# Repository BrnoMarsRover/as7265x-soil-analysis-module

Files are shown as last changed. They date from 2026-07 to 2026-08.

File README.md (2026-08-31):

# AS7265x Soil Analysis Module

> Multispectral soil-analysis subsystem developed for the **Brno Mars Rover / Freya** science payload.






<p align="center">
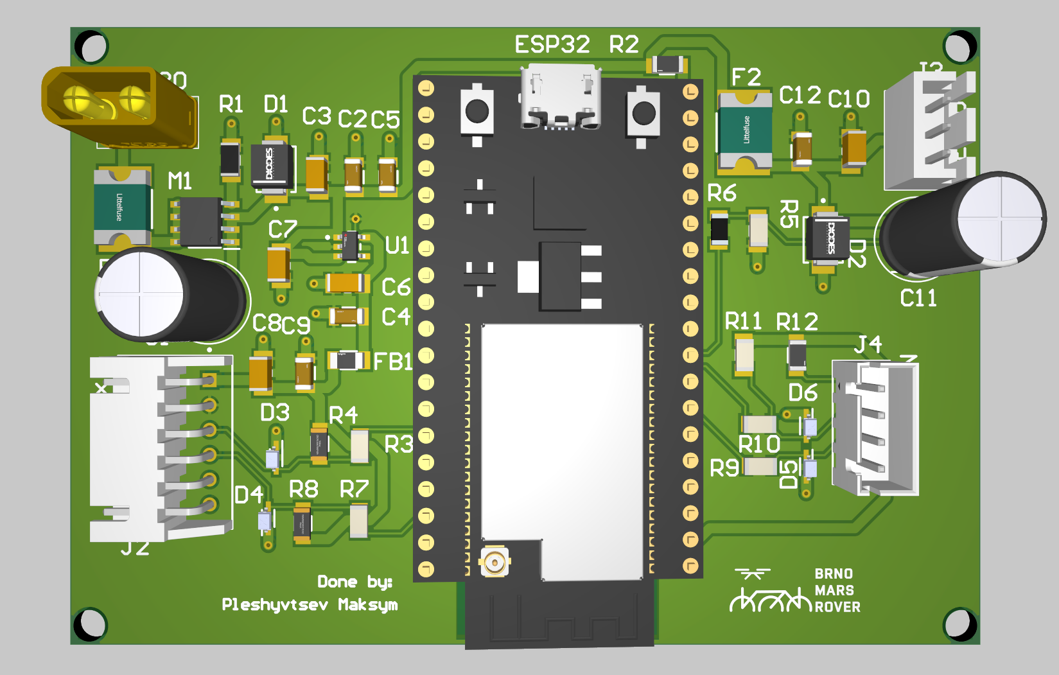
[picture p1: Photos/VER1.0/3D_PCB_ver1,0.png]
AS7265x Soil Analysis Module PCB V1.0
  
</p>

---

# 1. System Architecture & Sensor Task

## Overview

The **AS7265x Soil Analysis Module** is a rover-mounted subsystem for comparative multispectral analysis of soil and geological samples.

The system uses the **AS7265x 18-channel VIS-NIR spectral sensor** to measure reflected light between approximately **410 nm and 940 nm**. An ESP32 controls the sensor, a **four-slot sample carousel** driven by a Waveshare **ST3215** serial bus servo, and the illumination.

The ESP32 is a **passive command-controlled instrument**. It performs no automatic movement and no automatic measurement: the main computer is the mission controller and issues one JSON command at a time over the USB serial link. The ESP32 moves the carousel, reads the sensor and returns a raw spectrum; all scientific processing and all persistent sample data live on the main computer.

The project combines:

- custom PCB design;
- protected power distribution;
- embedded control;
- multispectral data acquisition;
- calibration and measurement methodology;
- spectral database development;
- mechanical and rover-system integration.

The current PCB V1.0 provides the core functionality required for the competition while remaining open to future sensor and hardware improvements.

---

## Engineering Scope

The project was developed from system concept to an assembled and operational hardware platform.

The engineering work includes:

- defining the overall science-module architecture;
- selecting the sensor, controller, actuator, connectors, and protection components;
- designing the complete schematic in Altium Designer;
- creating a custom two-layer carrier PCB;
- designing protected 5 V and 3.3 V power branches;
- integrating I²C, UART, PWM, and illumination interfaces;
- preparing the component BOM and purchasing documentation;
- assembling and debugging the first PCB revision;
- developing ESP32 firmware for sensor and servo control;
- creating a structured spectral material database;
- defining calibration and sample-preparation procedures;
- preparing the system for mechanical integration with the Freya rover.

---

## System Operation

The module is command-driven. Nothing moves and nothing is measured until the rover main computer asks for it.

1. The operator aligns physical Slot 1 with the loading hole and confirms it (`sync_position`).
2. `select_slot` brings the chosen slot to the loading hole, one 90 deg step per slot.
3. The PC creates a persistent Sample record with an ID and science metadata.
4. The external rover arm deposits soil; the operator confirms that it happened.
5. `measure_raw` rotates the same physical slot to the scanner, settles, and acquires one **raw** 18-channel spectrum.
6. The PC corrects that spectrum with the **fixed** stored dark and white references.
7. The normalized spectrum is compared against **every** material in the reference database.
8. An automatic, deliberately conservative interpretation is generated.
9. The complete scientific record is written to the PC archive — the same record opened in step 3.

```mermaid
flowchart LR
    SAMPLE[Soil sample in carousel slot]
    LIGHT[Controlled illumination]
    SENSOR[AS7265x spectral sensor]
    ESP[ESP32 hardware controller]
    SERVO[ST3215 serial bus servo, 4-slot carousel]
    PC[PC mission controller]
    BD[BD science layer]
    DATABASE[(database.json<br/>reference materials)]
    REFS[(references.json<br/>fixed white + dark)]
    STORE[(PC data/samples<br/>measured samples)]

    ESP -->|GPIO| LIGHT
    LIGHT --> SAMPLE
    SAMPLE -->|Reflected VIS-NIR light| SENSOR
    ESP <-->|I²C| SENSOR
    ESP -->|timed PWM| SERVO
    ESP -->|USB serial JSON: RAW spectrum| PC
    PC -->|raw| BD
    DATABASE --> BD
    REFS --> BD
    BD -->|normalized + matches| PC
    PC --> STORE
```

---

## Sample Carousel

The sample mechanism is a **four-slot carousel** on a full 360 deg axis,
driven by a Waveshare **ST3215 serial bus servo**. The ST3215 has a
4096-count absolute magnetic encoder and runs its own closed position
loop, so every movement is commanded in encoder counts and then
**verified by reading the encoder back**.

```
4 slots, 90 deg apart
loader and scanner exactly 180 deg apart = 2 slots

    load_slot = ((scan_slot - 1 + 2) % 4) + 1
```

The mapping is its own inverse: Slot 1 at the loader necessarily means
Slot 3 at the scanner.

### Two fixed positions

```
SCAN   the slot under the AS7265x
LOAD   the slot under the loading hole
```

A measurement swings the selected slot 180 deg to the scanner, acquires
WHITE, UV and IR spectra, and swings it 180 deg back, so the sample ends
exactly where it started.

### Software position tracking

The carousel has no limit switch, no Hall sensor and no physical index,
so nothing can tell the firmware which physical slot the operator calls
Slot 1. That is declared once, by hand, through option `[0]` — which
never moves anything. The declaration also captures the ST3215's encoder
reading, tying the logical model to a real measurement.

Position confidence is **runtime state and deliberately forgotten on
reset**. It is also dropped whenever the firmware can no longer vouch
for it: after a servo reconnect, after torque is released so the
carousel can be turned by hand, after a stop mid-movement, and after any
movement that fails to verify. Normal movement is then refused until the
operator re-synchronizes. The firmware never guesses.

### Logical geometry is not actuator calibration

One slot is 90 deg, always — even where the real mechanism needs a small
correction. The correction is a mechanical calibration; the 90 deg is a
fact about the carousel, and nothing tunes it.

### Fine alignment

Option `[5]` applies a small physical correction, bounded by
`MAX_FINE_ADJUST_DEG`. It does **not** renumber slots, redefine the
origin or act as a hidden whole-slot move: after a fine adjustment the
logical slot identity is exactly what it was.

### Safe measurement order

The sensor is proved usable **before** the mechanism moves. A sensor
fault should not leave a sample stranded at the scanner, and a carousel
that has already turned cannot un-turn to prove a point.

## Servo Calibration

Nothing here is a timing calibration. The ST3215 is commanded in encoder
counts and verified from the encoder afterwards, so the values in
`ESP32/config.py` are engineering settings rather than numbers to be
trimmed against a stopwatch:

| Setting | Meaning |
|---|---|
| `ST3215_MODE = 3` | step servo — the goal register IS a relative step count |
| `ST3215_SPEED` | goal speed in encoder steps per second |
| `ST3215_ACCELERATION` | start/stop ramp, in units of 100 steps/s^2 |
| `ST3215_POSITION_TOLERANCE` | how close counts as arrived |
| `ST3215_SETTLE_MS` | ring-down before the encoder reading that decides |

Step servo mode is what a carousel needs: a carousel turns forever in
one direction, and an absolute single-turn target would have to cross
the 4095/0 seam and send the mechanism the long way round.

`ST3215_POSITION_TOLERANCE` is **conservative and not yet measured on
the real mechanism**. Tighten it once the true repeatability is known —
but a tolerance that is too tight turns ordinary backlash into a failed
measurement.

## Main Features

- 18-channel spectral acquisition from approximately 410 nm to 940 nm;
- ESP32-based sensor and actuator control;
- four-slot 360° sample carousel with encoder-verified movement;
- deterministic USB-serial JSON command protocol for the main computer;
- persistent scientific sample storage on the main computer;
- fixed white and dark calibration references, never re-measured mid-run;
- comparison against every material in the spectral reference database;
- automatic, conservative interpretation of each measurement;
- USB programming and debugging through the ESP32 development board;
- protected 5 V rover power input;
- filtered 3.3 V sensor supply;
- separate protected servo power branch;
- MOSFET-controlled external illumination;
- JST-XH connectors for external modules;
- 1206 passive components for easier manual assembly.

---

# 2. Hardware

## Hardware V1.0

The final hardware is built around a custom two-layer carrier PCB connecting the ESP32 controller, AS7265x spectral sensor and carousel servo.

## Main Components

| Function | Component | Purpose |
|---|---|---|
| Controller | ESP-WROOM-32 development board with CP2102 | Sensor control, carousel control, USB serial communication and data processing |
| Spectral sensor | AS7265x multispectral triad | 18-channel VIS-NIR measurement |
| Servo | Waveshare ST3215 serial bus servo | Encoder-verified rotation of the four-slot sample carousel, on UART2 |
| Sensor regulator | TLV75533PDBVR | Protected 3.3 V sensor supply |
| Reverse-polarity protection | AO4407A | Protects the board from incorrect input polarity |
| Main and servo fuses | Littelfuse 2920L300/15DR | Resettable overcurrent protection |
| Input and servo TVS | SMBJ5.0A-13-F | Suppression of voltage transients |
| Sensor filtering | BLM31PG121SN1L | High-frequency noise filtering |
| Illumination switch | AO3400A | Low-side control of external illumination |
| Main power connector | XT30PB | Rover 5 V input |
| Signal connectors | JST-XH | Sensor, UART, servo and auxiliary connections |

---

## Power Architecture

The carrier PCB is powered from the rover's regulated **5 V rail**.

```text
XT30 5 V
   │
   ▼
Main resettable fuse
   │
   ▼
AO4407A reverse-polarity protection
   │
   ▼
+5V_PROTECTED
   │
   ├──► ESP32 development board
   │
   ├──► Servo branch
   │      ├─ resettable fuse
   │      ├─ TVS protection
   │      └─ local bulk / ceramic capacitance
   │
   └──► TLV75533 3.3 V LDO
          │
          ▼
       ferrite bead
          │
          ▼
      +3V3_SENSOR
          │
          ▼
       AS7265x
```

The input stage includes:

- resettable overcurrent protection;
- reverse-polarity protection;
- transient-voltage suppression;
- 1000 µF bulk capacitance;
- ceramic decoupling capacitors.

The servo branch is separated from the sensor supply to reduce the effect of servo current transients on spectral measurements.

> [!CAUTION]
> PCB V1.0 is designed for a regulated **5 V input**, not a higher-voltage battery rail.

---

## Electrical Interfaces

### AS7265x Sensor

The external AS7265x module is connected through a 6-pin JST-XH interface.

| Signal | ESP32 connection | Description |
|---|---|---|
| `+3V3_SENSOR` | — | Filtered 3.3 V sensor supply |
| `GND` | GND | Common ground |
| `ESP32_SDA` | GPIO21 | I²C data |
| `ESP32_SCL` | GPIO22 | I²C clock |
| `AS7265X_INT` | Configurable GPIO | Sensor interrupt |
| `AS7265X_RST` | Configurable GPIO | Sensor reset |

The I²C lines include series resistors and optional pull-up and ESD-protection positions.

### Rover UART connector (reserved)

The PCB carries a dedicated 3.3 V UART interface on UART2.

| Signal | ESP32 pin | Description |
|---|---|---|
| `UART2_TX` | GPIO17 | ESP32 transmit |
| `UART2_RX` | GPIO16 | ESP32 receive |
| `3V3_REF` | 3.3 V | Logic-level reference |
| `GND` | GND | Common ground |

> [!NOTE]
> **This connector is currently unused and reserved.** The competition system communicates over USB instead (see below), and the firmware never initializes a `machine.UART` peripheral. The hardware interface remains on the board for a future revision.

### Main-computer link (USB)

The competition connection is the ESP32 development board's USB port:

```text
Slot 1 at LOAD  →  Slot 5 at SCAN
Slot 2 at LOAD  →  Slot 6 at SCAN
Slot 3 at LOAD  →  Slot 7 at SCAN
...
```

The same cable both powers the ESP32 development board and carries the command protocol. Sensor and servo hardware are powered from the science board's protected rails as before.

Commands arrive on `sys.stdin` and responses leave on `sys.stdout`. The PC selects the baud rate (115200) when it opens the port; no pin or peripheral configuration is involved on either side.

### Servo

| Signal | Description |
|---|---|
| `+5V_SERVO` | Protected servo power |
| `GND` | Servo ground |
| `SERVO_PWM` | ESP32 PWM control (GPIO25) |

The servo connector has dedicated power protection and local bulk capacitance.

The ST3215 is reached over UART2 through a Waveshare Serial Bus Servo Driver Board: three wires and nothing else (TX GPIO17, RX GPIO16, GND). The servo is powered from an **external supply at the driver board** — no servo current flows through this PCB, and the firmware has no authority over servo power. The UART is opened lazily, on the first command, so powering up the ESP32 never drives the servo and can never nudge the carousel out of position.

---

# Hardware Gallery

## Schematics

| Power | ESP32 |
|:---:|:---:|
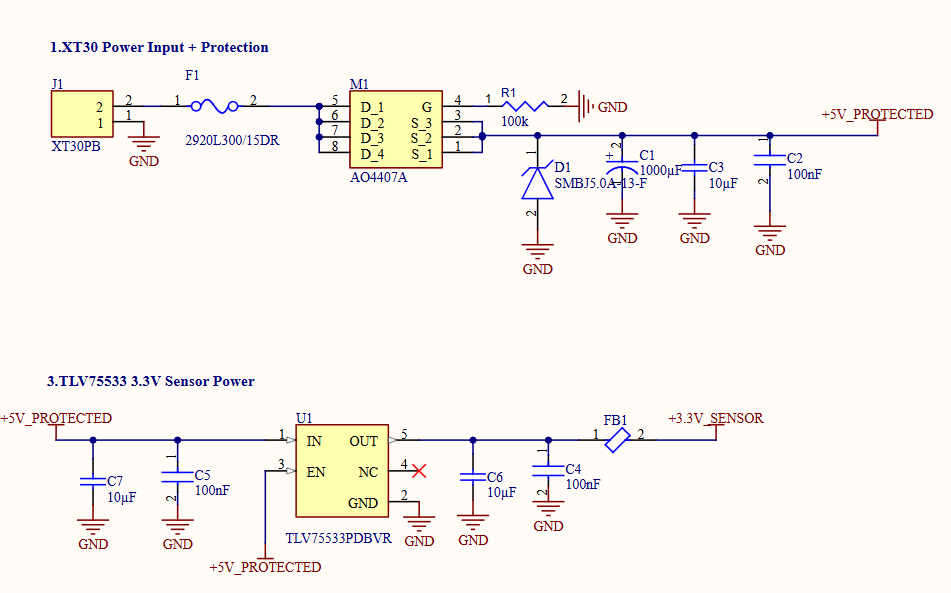
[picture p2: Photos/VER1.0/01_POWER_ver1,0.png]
Power schematic
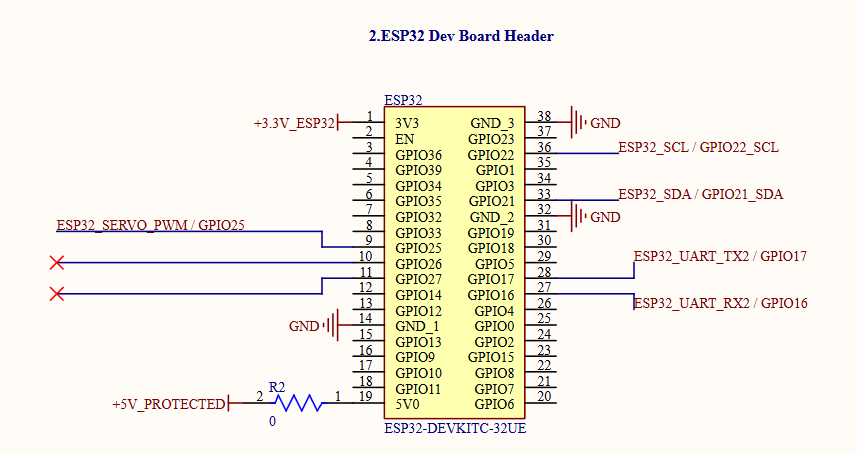
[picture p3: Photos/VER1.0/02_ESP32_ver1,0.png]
ESP32 schematic
|  |  |

## Connections & PCB Layout

| Connections | 2D PCB Layout |
|:---:|:---:|
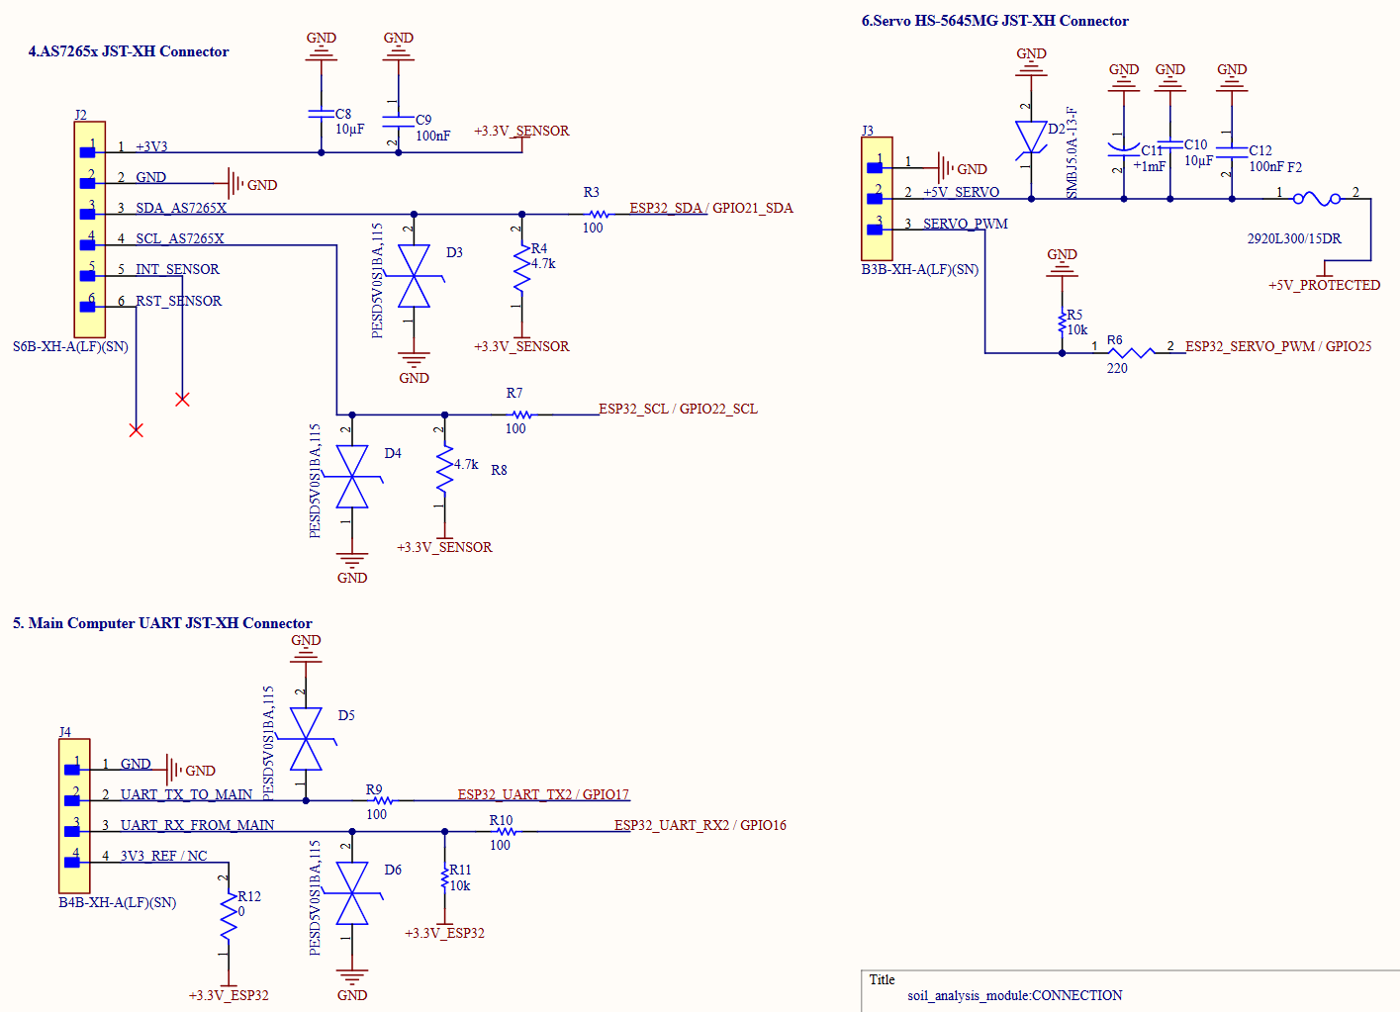
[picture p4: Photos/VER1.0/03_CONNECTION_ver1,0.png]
Connections schematic
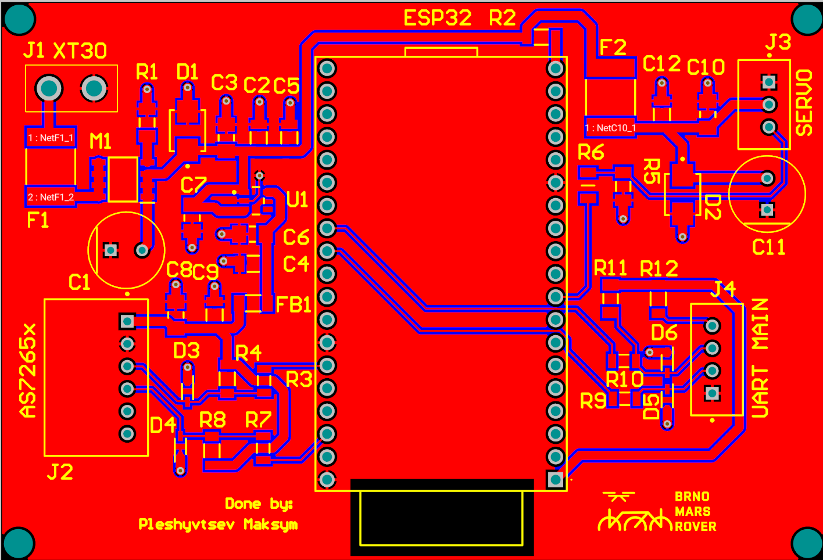
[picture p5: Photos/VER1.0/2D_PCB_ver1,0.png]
2D PCB layout
|  |  |

## Final Hardware

| Assembled PCB | Complete Rover Module |
|:---:|:---:|
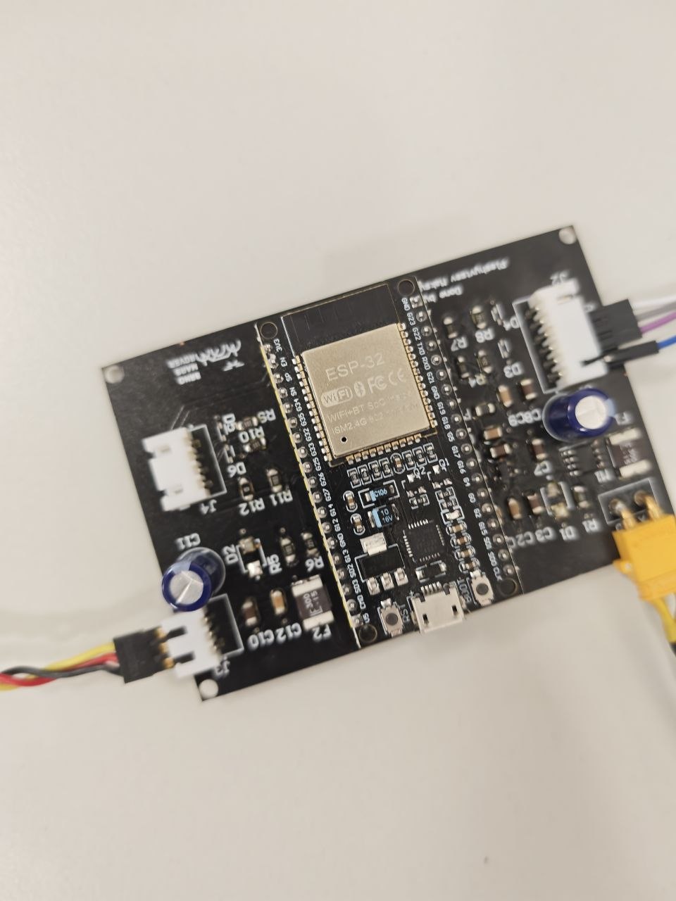
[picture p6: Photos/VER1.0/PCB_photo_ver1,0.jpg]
Assembled PCB V1.0
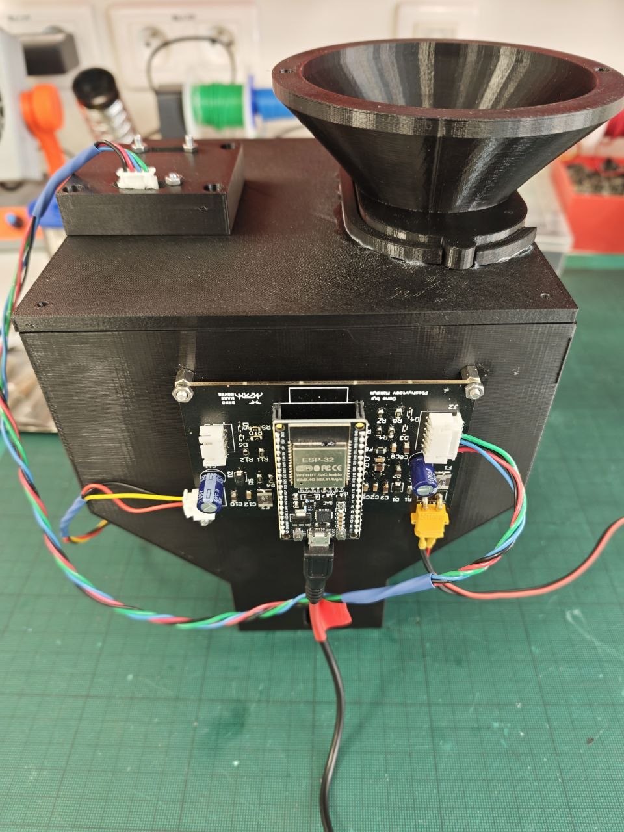
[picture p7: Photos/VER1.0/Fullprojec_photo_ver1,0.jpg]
Complete Freya AS7265x Soil Analysis Module
|  |  |

---

## Engineering Development Process

```text
Reflectance[i] =
    (Sample[i] - Dark[i])
    /
    (White[i] - Dark[i])
```

There is exactly **one** white reference and **one** dark reference for the whole competition run. Both live in [`firmware/BD/references.json`](firmware/BD/references.json), which is opened read-only and never written by any part of the system.

```json
{
  "white": { "A": 29.9166, "...": "...", "W": 61.7612 },
  "dark":  { "A": 0.0,     "...": "...", "W": 0.0 }
}
```

At startup the PC application loads the file, validates that both entries exist and that all 18 AS7265x channels are present and numeric, and reuses them for every sample. The ESP32 never sees this file; it does not need it to run the hardware.

Nothing measures white or dark: not at startup, not before a sample, not on any command. There is deliberately **no** "measure dark", "measure white" or "calibrate" command anywhere in the firmware or the application — the operator never performs calibration during normal operation.

The calibration set is identified as `FREYA_COMPETITION_2026_CAL_V1`, and every stored sample records that ID plus its provenance, so any record can be traced back to the references it was normalized against.

If the references are missing or invalid, the application still starts and **System Status** reports exactly what is at fault, while Measure Sample refuses to run rather than acquiring a spectrum that cannot be normalized.

Each measured sample stores three spectra, so a measurement can be re-derived later:

| Stored spectrum | Content |
|---|---|
| `raw` | Exactly what the AS7265x returned |
| `dark_corrected` | `Sample - Dark`, per channel |
| `normalized` | `(Sample - Dark) / (White - Dark)` |

Negative dark-corrected values are kept as they are. A channel reading below the stored dark reference is real information about noise or drift, and clamping it to zero would hide that from the operator.

PTFE is planned as the primary stable white-reference material.

---

## Software Architecture

```text
firmware/
├─ ESP32/    MicroPython hardware controller
├─ BD/       PC-side spectral processing / database
├─ PC/       mission controller / operator application
└─ OPERATIONS.md
```

The software is divided into three functional layers:

```text
                    MAIN COMPUTER
                         │
              ┌──────────┴──────────┐
              │                     │
              ▼                     ▼
             PC                     BD
     Mission Controller      Science / Database
              │                     ▲
              │ raw spectrum        │
              └─────────────────────┘
              │
              │ USB / CP2102
              │ newline JSON
              ▼
            ESP32
      Hardware Controller
              │
        ┌─────┴─────┐
        ▼           ▼
     ST3215       AS7265x
     Carousel      Sensor
```

| Layer | Runs on | Owns |
|---|---|---|
| `firmware/ESP32/` | MicroPython on the ESP32 | carousel, servo, AS7265x, **raw** 18-channel acquisition, hardware status |
| `firmware/BD/` | CPython on the PC | fixed White/Dark, material database, dark correction, normalization, comparison, interpretation |
| `firmware/PC/` | CPython on the PC | operator interface, Sample lifecycle, persistent Sample archive, orchestration |

The boundaries are strict and enforced by the test suite:

- ESP32 imports nothing from `BD/` or `PC/`, and needs no JSON data file to move hardware or read the sensor.
- BD depends on no serial port, no I2C, no carousel and no long-lived measurement object — it is pure data processing.
- PC reaches the ESP32 **only** over the serial protocol, and BD **only** by import.

**The ESP32 does not know what material a sample resembles.** It moves hardware, reads hardware, and reports hardware.

---

## ESP32 Firmware

MicroPython executes `main.py` automatically after boot. That startup
does **not** move the servo, measure anything, or touch a peripheral at
all: it builds the runtime state, builds the protocol and serves.
Measured on hardware, the board answers `ping` **3 ms** after boot.

A missing sensor, an unpowered servo and an unsynchronized carousel are
states the protocol *reports* — never conditions for it to run. That is
the point: a board that cannot be reached cannot be diagnosed.

```text
0x49
```

Current acquisition configuration:

```text
firmware/ESP32/
├─ boot.py       deliberately empty, and explains why
├─ main.py       build the runtime state, build the protocol, serve
├─ config.py     every hardware constant, once
├─ sensor.py     AS7265x driver + the one sensor runtime lifecycle
├─ servo.py      ST3215 wire protocol, driver and connection gate
├─ carousel.py   4-slot geometry and logical position
└─ protocol.py   newline-JSON framing, dispatch, and all 25 commands
```

Seven files, flat — no packages. Every one is named in the deployment
manifest in `firmware/tools/device.py`, and nothing outside that
manifest is ever uploaded.

### One sensor lifecycle

There is exactly one path to a working sensor:

```text
create I²C
   ↓
scan bus
   ↓
verify 0x49
   ↓
verify internal AS7265x devices
   ↓
apply configuration
   ↓
read configuration back
   ↓
READY
```

A failed sensor initialization at boot is not permanently latched. Later sensor commands can retry the complete bring-up sequence.

---

## Acquisition Sequence

```text
ensure sensor ready
        ↓
AS7265x onboard white LED ON
        ↓
300 ms illumination settle
        ↓
start new integration
        ↓
wait DATA_READY
        ↓
read 18 calibrated channels
        ↓
validate spectrum
        ↓
AS7265x onboard white LED OFF
        ↓
return RAW spectrum
```

The LED shutdown is executed through a protected cleanup path so a failed acquisition does not intentionally leave the illumination enabled.

---

## Command Protocol

Communication uses newline-delimited JSON over USB / CP2102.

| Command | Function |
|---|---|
| `ping` | Liveness check |
| `get_status` | Sensor, carousel, servo and physical slot state |
| `sync_position` | Declare the origin: Slot 1 at the loading hole (moves nothing) |
| `select_slot` | Choose the physical slot and bring it to the loader |
| `move_slots` | Whole-slot movement, exactly 45° per slot |
| `fine_adjust` | Small alignment correction in degrees; logical slot unchanged |
| `clear_slot` | Free a physical slot; the PC's scientific record is untouched |
| `measure_raw` | Swing to the scanner and acquire one RAW 18-channel spectrum |
| `sensor_test_raw` | Exercise the whole sensor path and return RAW; moves nothing |
| `servo_stop` | Brake the servo and release the pin |

There is deliberately no `measure_sample`, no `list_samples`, no `get_references` and no `get_database_status`. Those are science and persistence, and they live on the PC.

A successful `measure_raw` response:

```json
{
  "request_id": "42",
  "ok": true,
  "data": {
    "slot_id": 1,
    "sample_id": "S001",
    "raw": {"A": 1.23, "B": 2.34, "...": "...", "W": 4.56},
    "sensor_settings": {
      "integration_cycles": 100,
      "gain": 2,
      "gain_x": "16x",
      "measurement_mode": 2,
      "led_current": 1
    },
    "carousel": {"selected_slot": 1, "carousel_phase": "SCAN"}
  }
}
```

Every payload is JSON-safe primitives only. Exceptions are never serialized; they become `code`, `message`, `stage`, `exception_type` and `exception_message` fields.

### Failure semantics

- A sensor fault is detected **before** the carousel moves, so a broken sensor never strands a sample at the scanner.
- If acquisition fails after the swing, the firmware returns the mechanism to the loader and says so — or, if it cannot, invalidates position tracking rather than reporting a position it no longer knows.
- If the ESP32 fails before RAW is obtained, the PC leaves the sample `LOADED`. No false `MEASURED` state is ever written.
- If RAW arrives but the PC-side analysis fails, the spectrum is still saved with `analysis_status: "FAILED"` and the exact error. Acquired science survives downstream software failure.

---

## BD — Science Layer

`firmware/BD/` runs on the main computer and is never uploaded to the ESP32.

```text
firmware/BD/
├─ references.json     one fixed White + one fixed Dark   PROTECTED, READ ONLY
├─ database.json       22 reference material spectra       PROTECTED, READ ONLY
├─ config.py           calibration ID, thresholds, precision
├─ database.py         reference loading, cosine similarity, comparison
└─ sample_analysis.py  validation, the two formulas, interpretation
```

> [!CAUTION]
> `database.json` and `references.json` are authoritative scientific assets. Normal operation never writes to them, and neither `References` nor `MaterialDatabase` has a save path at all. Regenerating either would silently invalidate every measurement taken against it.

### Calibration model

The competition uses **one** accepted White and **one** accepted Dark for the whole run, stored in `references.json` under a single calibration ID. The operator is never asked to measure White or Dark, and nothing at runtime can re-measure them. That is what makes two samples taken hours apart comparable.

```text
S = raw sample spectrum from the ESP32
D = fixed Dark
W = fixed White

C = S - D                 dark corrected
R = (S - D) / (W - D)     normalized reflectance
```

Applied per channel, across all 18. Negative results are **kept**: a channel reading below the stored dark reference is real information about noise or drift, and clamping it to zero would hide that. Where `W == D` the reflectance is undefined and reported as `0.0`, with the affected channels named.

### Pure functions, no shared state

```python
validate_spectrum(raw)
dark_correct(sample, dark)
normalize(sample, dark, white)
database.compare(normalized)
interpret(matches)
```

Every one takes plain dictionaries and returns plain dictionaries. No `SoilMeasurementSystem`, no object whose `sample_data` can be `None` while a spectrum exists elsewhere. The `'NoneType' object has no attribute 'sample_data'` class of bug is structurally impossible here, because there is no shared object to disagree with itself.

### Comparison

The normalized spectrum is compared against **every** material in the database by cosine similarity, sorted best first. The complete ranking is stored with the sample; the interface decides how many rows to show.

---

## Automatic Interpretation

A compact written conclusion is generated from the best match, the second-best match, and the gap between them.

```text
STRONG_REFERENCE_MATCH   clear leader
AMBIGUOUS                top two candidates too close to separate
WEAK_REFERENCE_MATCH     nothing in the database is a good fit
NO_DATABASE              no reference materials available
```

Both thresholds live in `firmware/BD/config.py` and are recorded inside each sample record, so old results stay interpretable after retuning:

```python
MIN_SIMILARITY_PERCENT   = 85.0
AMBIGUITY_MARGIN_PERCENT = 1.5
```

> [!NOTE]
> These are **heuristic competition-support thresholds, not scientifically validated criteria**. Because cosine similarity between non-negative reflectance vectors is high for almost any pair, the informative quantity is the *gap* between the top candidates rather than the absolute score. Tune both against measurements of known materials.

The wording is deliberately constrained. This module performs **comparative spectral classification** against a small reference library. It reports spectral similarity, match scores and reference matches — never chemical probability, composition percentages or identification certainty.

Example output:

```text
The measured spectrum shows the highest cosine similarity to Red Clay
(91.4%). Bentonit is the second closest reference (87.2%). Because the
score difference is only 4.2 percentage points, the classification is
considered ambiguous.
```

---

## PC — Mission Controller

`firmware/PC/` is standard CPython.

```text
firmware/PC/
├─ rover_science_client.py   entry point: parse, open one port, hand over
├─ serial_link.py            the ONE serial owner
├─ requirements.txt          pyserial, mpremote
└─ workflow/
    ├─ prompts.py            the only input() in the project
    ├─ display.py            results into tables
    ├─ session.py            the link, the stores, the science layer
    ├─ calibration.py        making and choosing a calibration
    ├─ carousel.py           servo setup, alignment, diagnostics
    ├─ measure.py            the measurement sequence
    ├─ records.py            the archive, and ground truth
    └─ screen.py             the main screen and the menu loop
```

Completed scientific records live in `firmware/BD/samples/`, not beside
the client: a laptop is a place a program runs, not a place scientific
evidence lives. The PC orchestrates saving and reading them.

BD and Science are imported by path relative to the application, so it
runs from any working directory with no `PYTHONPATH` setup.

### Sample lifecycle

```text
EMPTY
  ↓
READY_TO_LOAD
  ↓
LOADED
  ↓
MEASURED
```

`MEASURED` is **not** `EMPTY`. The soil physically stays in the slot until the operator clears it. Clearing a physical slot frees the mechanism and keeps the scientific record; deleting a Sample is a separate, explicitly confirmed action.

The record opened by *Prepare* is the record completed by *Measure*. One coherent scientific object per sample — no second Sample ID is ever created during measurement.

### Sample record

Each record holds the Sample ID and slot, the lifecycle state, PC-supplied timestamps, mission metadata, all three spectra across all 18 channels, the sensor settings *read back from the sensor*, the calibration provenance, the ranked match against every database material, and the automatic interpretation.

Raw is primary data and is never overwritten by anything derived from it. `raw`, `dark_corrected` and `normalized` are stored separately, which is what makes offline re-analysis possible: a stored spectrum can be re-run later against different thresholds, an updated material database or a different accepted calibration, without repeating the physical acquisition.

Writes go through a temporary file and an atomic rename. A present-but-unparseable index is reported and every write refused, rather than overwritten — data that looks damaged is usually still recoverable by hand.

The PC supplies every timestamp, because the ESP32 has no reliable wall clock and never invents one:

```python
datetime.now(timezone.utc).isoformat()
```

Mission metadata is task, hypothesis, location, map point, note and photo reference. Every field is optional; an unanswered field stays `null` rather than being invented to satisfy a prompt. Photos are never stored — only a filename, ID or path.

### Operator interface

```text
============================================================
 FREYA SCIENCE MODULE
============================================================

Selected: Slot 1 / S001
State:    LOADED
Position: LOAD

Loader: Slot 1    Scanner: Slot 5

1  S001     LOADED
2  ----     EMPTY
...

[1] Choose Sample / Slot
[2] Prepare Sample [DONE]
[3] Confirm Sample Loaded [DONE]
[4] Measure Sample [AVAILABLE]
[5] Fine Carousel Alignment

[t] Tools / Records
[h] Help
[q] Exit
```

Everything secondary lives behind `[t]`: Sample Database, System Status, Re-sync Carousel, Servo / Carousel Test, Sensor Test, Clear Physical Slot, Import ESP32 Acquisitions, Decision Learning Database.

**The Sample Database shows all three stores at once.** A Sample can be on the ESP32, in the PC session, in the PC archive, or in any combination, and the table has a column for each:

```text
#    Sample       Slot  ESP32  SESSION  ARCHIVE  State       M   A Interpretation
1    s01          1     yes    yes      yes      MEASURED    1   1 iron_oxide
2    s02          2     yes    yes       -       MEASURED    1   1 AMBIGUOUS_SET
```

Every destructive option names exactly one store — *Delete a sample from the ESP32*, *…from the PC session*, *…from the PC archive*, *Delete ALL samples from the ESP32*, *Clear the PC session working set* — and every confirmation prints what survives it. There is deliberately no "Delete sample".

**Sensor Test is one command.** The operator never has to decide which internal layer to test: it runs the whole chain — ESP32 sensor recovery, I2C, internal devices, configuration, illumination, a new 18-channel acquisition, then the PC's dark correction, normalization and database comparison — through the production code path, prints every stage as PASS or FAIL, and saves nothing.

For installation, upload, startup and recovery procedures, see **[firmware/OPERATIONS.md](firmware/OPERATIONS.md)**.

---

## Competition Workflow

```text
INITIAL CAROUSEL CALIBRATION   Slot 1 under the loading hole, declared once
    ↓
CHOOSE SLOT                    ESP32 brings the slot to the loading hole
    ↓
PREPARE SAMPLE                 PC creates the persistent record
    ↓
external rover arm deposits soil
    ↓
CONFIRM LOADED                 state = LOADED
    ↓
MEASURE SAMPLE
    ↓        ESP32   180° swing to the scanner
    ↓        ESP32   RAW 18-channel acquisition
    ↓        PC      receives RAW
    ↓        BD      validation, C = S - D, R = (S-D)/(W-D)
    ↓        BD      comparison against ALL materials, interpretation
    ↓        PC      completes the SAME record in the SESSION
    ↓
state = MEASURED, soil still physically in the slot
    ↓
    ↓        the acquisition is now in TWO places:
    ↓          ESP32     its own RAM buffer, until the board resets
    ↓          SESSION   the PC's working set for this run
    ↓
    ↓        the PC ARCHIVE is NOT touched. It never is, without
    ↓        an explicit import.
    ↓
operator adds location, map point, photo, notes
    ↓
IMPORT                         explicitly, when the result is worth keeping
    ↓        from the ESP32, or from the session working set
    ↓        a COPY - the source keeps its own record
    ↓
REPORT
```

**Why the session exists at all.** RAW that lives only in ESP32 RAM is one board reset from being gone — and opening the serial port resets the board, so a PC client that crashed and restarted would take the spectrum with it. The session file means a crash costs an ANALYSIS and not an EXPERIMENT. It is durable scaffolding, not an archive: the archive is what the operator has decided to keep.

A typical mid-run state:

```text
Slot 1   S001   MEASURED
Slot 2   S002   LOADED
Slot 3   ----   EMPTY
Slot 4   ----   EMPTY
Slot 5   S003   MEASURED
Slot 6   ----   EMPTY
Slot 7   ----   EMPTY
Slot 8   ----   EMPTY
```

---
## Spectral Material Database

A dedicated database is being developed for calibration, comparison, and future classification algorithms.

The database contains:

### Martian and Geological Analogs

- iron oxides;
- iron sulfate;
- magnesium sulfate;
- sulfur;
- gypsum;
- calcium and magnesium carbonates;
- kaolin;
- bentonite and smectite clays;
- quartz sand;
- dolomite;
- terrestrial soils and mineral mixtures.

### Optical References

- PTFE white reference;
- magnesium oxide;
- calcium carbonate;
- activated carbon;
- black iron oxide.

### Organic and Contamination References

- citric acid;
- ascorbic acid;
- tartaric acid;
- cornstarch;
- peat;
- PET plastic;
- wood ash;
- rover-related contamination materials.

A recommended database record contains:

```csv
timestamp,
sample_id,
material,
preparation,
distance_mm,
mass_g,
integration_time,
gain,
ch_410,
ch_435,
ch_460,
ch_485,
ch_510,
ch_535,
ch_560,
ch_585,
ch_610,
ch_645,
ch_680,
ch_705,
ch_730,
ch_760,
ch_810,
ch_860,
ch_900,
ch_940
```

The database is intended for training and validating comparative classification methods. It does not provide definitive chemical identification from a single spectrum.

`firmware/BD/database.json` holds **known reference materials only**. Measured competition samples are stored separately under `firmware/PC/data/`, and nothing in the system writes to the reference database.

Each measurement is compared against every entry in the database, and all results are stored ranked by descending similarity — not only the top few.

> [!IMPORTANT]
> The match percentage is **cosine similarity**, not composition and not probability.
>
> Correct: `Highest spectral similarity: Red Clay — 92.1%`
> Incorrect: `The sample is 92.1% Red Clay.`

---

## Development Process

The module was developed through the following stages:

1. **System definition**  
   Sensor, controller, actuator, communication, power, and mechanical requirements were defined.

2. **Component selection**  
   Components were selected according to electrical requirements, availability, package size, protection level, and manual assembly constraints.

3. **Schematic design**  
   Separate power, controller, and external-interface schematic sections were created in Altium Designer.

4. **PCB layout**  
   The board was routed as a two-layer PCB with a ground plane, protected power branches, mounting holes, and accessible external connectors.

5. **Manufacturing and assembly**  
   Gerber files were generated, the PCB was manufactured, and components were assembled manually.

6. **Firmware integration**  
   ESP32 firmware was developed to operate the spectral sensor and sample-handling servo.

7. **Scientific validation**  
   White-reference measurements, spectral acquisition, material selection, and database preparation were performed.

---

## Current Project Status

### Implemented

- assembled PCB V1.0;
- protected power-input architecture;
- ESP32 carrier-board integration;
- AS7265x communication;
- multispectral channel acquisition;
- ST3215 serial bus servo driver with encoder-verified movement;
- four-slot carousel state model with explicit position confidence;
- USB-serial JSON command protocol (CP2102 console, no UART peripheral);
- three-layer software split: ESP32 hardware / BD science / PC mission control;
- single authoritative sensor lifecycle with automatic recovery;
- verified sensor configuration, read back from the registers;
- persistent sample storage on the PC;
- fixed white/dark reference calibration;
- comparison against the full reference-material database;
- automatic conservative interpretation;
- main-PC application with a reusable serial API;
- external illumination control architecture;
- rover UART hardware interface (reserved for a future revision);
- structured spectral-material database;
- mechanical mounting provisions.

### Ongoing Work

- servo calibration on the assembled mechanism (neutral pulse, direction, 45° step timing);
- final rover mechanical integration;
- measurement repeatability testing;
- distance-dependent spectral correction;
- tuning the interpretation thresholds against known materials;
- integration of the client API into the rover main software.

---

## Planned V1.1 Improvements

Future hardware revisions are planned to include:

- VL53L4CD time-of-flight distance sensor;
- automatic recording of sample height and sensor distance;
- optional load-cell support;
- external HX711 validation;
- possible NAU7802 integration;
- improved servo and logic power separation;
- additional test points;
- improved connector labelling;
- revised power protection;
- activation of the reserved UART2 rover connector as an alternative to USB;
- expanded automated calibration and data logging.

The distance sensor is considered the highest-priority measurement extension because spectral intensity depends strongly on sensor-to-sample geometry.

The load cell is planned as optional experimental metadata rather than a requirement for the current competition task.

---

# Repository Structure

```text
as7265x-soil-analysis-module/
├─ README.md
├─ Photos/
│  └─ VER1.0/
│     ├─ 01_POWER_ver1,0.png
│     ├─ 02_ESP32_ver1,0.png
│     ├─ 03_CONNECTION_ver1,0.png
│     ├─ 2D_PCB_ver1,0.png
│     ├─ 3D_PCB_ver1,0.png
│     └─ PCB_photo_ver1,0.jpg
├─ Hardware/            Altium project and manufacturing outputs
│  ├─ Altium/
│  └─ Manufacturing/
├─ firmware/
│  ├─ ESP32/            MicroPython hardware controller (the only uploaded code)
│  ├─ PC/               operator workflow, orchestration, the one serial owner
│  ├─ Science/          every scientific formula, and the Decision Model
│  ├─ BD/               calibration, DB1/DB2/DB3, training data, Sample records
│  ├─ Tests/            software/ runs the real firmware on CPython;
│  │                    hardware/ needs a real board and turns the carousel
│  ├─ tools/            device.py - deploy and verify the ESP32
│  └─ research/         non-production: experiments, ERC planning, training
└─ Documentation/
   ├─ ARCHITECTURE.md          the system model and the layer rules
   ├─ OPERATIONS.md            run, deploy, diagnose, recover
   ├─ SCIENCE.md               the scientific method
   ├─ DATABASES.md             DB1 / DB2 / DB3 and their provenance
   └─ DECISION_ARCHITECTURE.md how a conclusion is reached
```

Manufacturing outputs should be stored separately for each PCB revision:

```text
Hardware/Manufacturing/
├─ V1.0/
└─ V1.1/
```

---

# Documentation

Project documentation includes:

- PCB architecture and component models;
- consolidated BOM;
- component purchasing list;
- spectral material database;
- PCB schematic and layout images;
- manufacturing files;
- firmware and measurement data.

Recommended repository links:

- [Operations runbook](firmware/OPERATIONS.md) — install, upload, run, debug, recover
- [PCB BOM and component models](Documentation/Mars%20Rover%20AS7265x%20Soil%20Analyzer%20PCB%20-%20BOM%20_%20Component%20Models%20v0.1.pdf)
- [PCB purchase list](Documentation/Purchase%20List%20-%20Mars%20Rover%20AS7265x%20PCB.docx)
- [Spectral material database](Documentation/Spectral%20Material%20Database.docx)

Document roles are kept separate on purpose:

| Document | Answers |
|---|---|
| `README.md` | what the project is, how it is built, what the science means |
| `firmware/OPERATIONS.md` | how to install, run, update, debug and recover it |
| source code | how the implementation works |

---

## Long-Term Development

After the current competition system is completed, possible development directions include:

- acquire repeatable 18-channel VIS-NIR spectra;
- normalize measurements against White/Dark references;
- compare spectral shape with a controlled material library;
- preserve both RAW and processed data.

It does **not** claim exact chemical composition, concentration or laboratory-grade mineral identification.

---

## License

No open-source license has currently been selected.

Until a `LICENSE` file is added, the project should be treated as **all rights reserved**.

---

## Acknowledgements

Developed as part of the **Brno Mars Rover / Freya** student rover project.

---

## Author

**Maksym Pleshyvtsev**  
Electronics and Communication Technologies Student  
Brno University of Technology — FEKT

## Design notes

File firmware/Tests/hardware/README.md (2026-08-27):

# Hardware verification

Real hardware. A real CP2102, a real ESP32, a real ST3215, a real
AS7265x, and a carousel that turns.

> ## Status: NO HARDWARE HAS BEEN EXECUTED
>
> Every one of the **107 registered tests** is `NOT_RUN`, across **13
> campaigns** and **113 requirements**. 94 are `READY_FOR_HARDWARE` —
> their definitions, prerequisites, capabilities and configuration have
> all been checked offline and they will execute the moment a board is
> connected. 13 are `BLOCKED`, and every one of them is blocked on
> something you can supply: a field in the bench profile, an instrument,
> a fixture, or the test-side diagnostic agent.
>
> **Nothing in this directory is evidence about the hardware.** The
> framework's own test suite passes — 1,678 checks against a fake
> transport — and that says the harness is ready. It says nothing about
> a carousel.
>
> Start at [RUNBOOK.md](RUNBOOK.md) when the module is on the bench.

---

## What a result says now

A single status could not tell these apart, so there are three
independent axes and `status` is a projection of them:

| Axis | Values | Question it answers |
| --- | --- | --- |
| readiness | `READY` `BLOCKED` | could the procedure start? |
| execution | `NOT_RUN` `RUNNING` `COMPLETED` `ABORTED` `ERROR` | what happened once it did? |
| verdict | `NOT_EVALUATED` `PASS` `FAIL` `INCONCLUSIVE` `CHARACTERIZATION` | what does the evidence say about the hardware? |

The two the old model could not express are the ones that matter most:

- **`INCONCLUSIVE`** — the procedure ran and a required observation was
  missing or ambiguous. An operator who answered UNKNOWN; a field the
  firmware did not return; a fault injected outside its target window.
  Not a failure, and emphatically not a pass.
- **`CHARACTERIZATION`** — measurements were collected and no
  authoritative requirement exists to judge them. Most of B4 is this
  until somebody writes down what the closing error is allowed to be.
  Of 113 requirements, **33 have no authoritative source** and say so;
  those can only ever characterize.

**A `PASS` needs five things**, and each was a way to fake one before:
the body completed, at least one check was made, every check passed,
every `REQUIRED` observation was actually obtained, and the run met its
own declared qualification sample size.

---

## Why this is separate from `Tests/software`

`Tests/software` is 40 suites and 3495 checks that run against fake
hardware. It proves the firmware's logic and proves nothing about the
wiring, the servo, the sensor or the mechanism. This campaign is the
other half.

The separation is not tidiness. `run_all.py` is the command run by
reflex — in a hook, from an editor, by someone who is not standing next
to the mechanism — and the carousel may be holding samples or be
mechanically constrained. **A test suite that can turn an actuator must
never be reachable by reflex.** So:

- `Tests/run_all.py` cannot reach this tree.
- The default invocation of `run_hardware_tests.py` prints a list and
  exits.
- There is no default port and there will not be one.
- A real run needs `--confirm-hardware`, and then a second, specific
  confirmation for whatever class of test was selected.
- The only files under `Tests/hardware/` named `test_*.py` are in
  `offline_tests/`, and every one of them runs on a fake transport.

Tripwires around `serial.Serial`, `serial.serial_for_url`,
`list_ports.comports`, `SerialLink.open`, `SerialLink.hard_reset`,
`SerialLink.available_ports`, `os.open` on any device path, and
`subprocess` invocation of mpremote, esptool, ampy, rshell or the
diagnostic agent confirm that import, `--help`, `--list`,
`--describe`, `--capabilities`, every campaign dry run and the entire
offline suite perform **zero** hardware operations. Each tripwire
raises; one that merely counted could be called and ignored.

---

## Installation

Python 3.8 or newer, and the same `pyserial` the operator client uses:

```bash
python3 -m pip install -r firmware/PC/requirements.txt
```

On a fresh Linux account, before the first real run:

```bash
sudo usermod -aG dialout $USER
```

then log out and back in — group membership is read at login. See
`PORT_DENIED` in `Documentation/OPERATIONS.md`.

---

## Configuration

Copy the example and edit the copy. Your copy is git-ignored; the
example is tracked.

```bash
cp firmware/Tests/hardware/configuration/profile.example.json firmware/Tests/hardware/configuration/my-bench.json
```

The profile describes the bench: which device, at which baud, with which
limits. It does **not** duplicate the firmware's constants —
`firmware/ESP32/config.py` is read directly, so the campaign always
qualifies the numbers the firmware actually uses.

The profile keeps three kinds of number apart, and the distinction
matters more than it looks:

| Provenance | Meaning | Example |
| --- | --- | --- |
| `CONFIGURED` | what the firmware does, true by definition | `ST3215_POSITION_TOLERANCE = 15` |
| `ASSUMED` | what we believe the mechanism is, unmeasured | 4096 counts per revolution; a 1.0 gear ratio |
| `MEASURED` | what a hardware test actually observed | filled in by B3 and B4 |

H-002 exists because at least one `ASSUMED` value may be wrong.

**There is no default port.** `/dev/ttyUSB0` is an enumeration order,
not a name: plug in a second USB serial device and the science module
moves to `ttyUSB1` with nothing visibly changing. The profile names a
`/dev/serial/by-id` path, a USB serial number, or a VID/PID — and an
ambiguous selector is an error, never a choice.

---

## Safe commands — these touch nothing

```bash
python3 firmware/Tests/hardware/run_hardware_tests.py --list
```

```bash
python3 firmware/Tests/hardware/run_hardware_tests.py --describe HW-B3-001
```

```bash
python3 firmware/Tests/hardware/run_hardware_tests.py --capabilities
```

```bash
python3 firmware/Tests/hardware/run_hardware_tests.py --dry-run --all
```

`--dry-run` checks every gate that can be checked without a device:
the definition, the prerequisites, the capabilities and the profile. It
does not execute a single test body and opens no transport, so a dry
run **cannot** produce hardware evidence. Its artifacts are stamped
`DRY_RUN / NO_HARDWARE_EVIDENCE` in the directory name, the manifest and
every event line.

The framework's own tests:

```bash
python3 firmware/Tests/hardware/offline_tests/run_offline.py
```

---

## Running one real test, later

### The first run bootstraps the profile

A profile identifies the board by its stable USB identity — and the way
to *learn* that identity is `HW-B0-004`, which needs a profile. So the
very first run is bootstrapped with an explicit device, for the
inventory only:

```bash
python3 firmware/Tests/hardware/run_hardware_tests.py --run HW-B0-004 --confirm-hardware --port /dev/ttyUSB0
```

That test opens nothing — it enumerates what the OS already knows. Read
`usb_serial_number` out of the run's `measurements.csv`, put it in your
profile, and use `--profile` from then on. After that the campaign never
has to be told a device name again, and cannot open the wrong board.

### Every run after that

```bash
python3 firmware/Tests/hardware/run_hardware_tests.py --profile firmware/Tests/hardware/configuration/my-bench.json --run HW-B0-001 --confirm-hardware
```

A whole campaign:

```bash
python3 firmware/Tests/hardware/run_hardware_tests.py --profile firmware/Tests/hardware/configuration/my-bench.json --run-campaign B1 --confirm-hardware
```

### Every option

| Option | Effect |
| --- | --- |
| `--list` | the catalogue. Touches nothing. |
| `--describe TEST-ID` | one complete definition. Touches nothing. |
| `--capabilities` | what the production system can and cannot be asked, and why |
| `--dry-run` | check every offline gate for the selection |
| `--run TEST-ID` | run one test. Repeatable. |
| `--run-campaign B3` | run a whole campaign. Repeatable. |
| `--all` | select everything |
| `--confirm-hardware` | **required** for any real run |
| `--port DEVICE` | an exact device, overriding the profile's selector |
| `--profile PATH` | the bench profile |
| `--iterations N` | override the repeat count, bounded by each test and by the profile |
| `--output PATH` | where the evidence directory goes |
| `--non-interactive` | never prompt; tests needing a human become `BLOCKED` |
| `--resume RUN-ID` | skip tests that already passed on hardware in that run |
| `--stop-on-failure` | stop at the first `FAIL`, `ERROR` or `ABORT` |
| `--expert-override` | bypass a layer gate — needs `--override-reason` and a confirmation |
| `--json` | machine-readable `--list`, `--describe`, `--capabilities` |
| `--verbose` | print every check, not only the failures |

Exit codes: `0` clean, `1` a failure, `2` a usage or configuration
error, `3` a real run without `--confirm-hardware`, `4` aborted,
`5` something was blocked.

---

## What a result means

| Status | Meaning |
| --- | --- |
| `NOT_RUN` | nobody has looked at it |
| `READY_FOR_HARDWARE` | every offline gate passes; it runs when a board is connected |
| `SKIPPED` | a precondition that is nobody's fault, or a declined confirmation |
| `BLOCKED` | it cannot run, and the reason is named — a missing production interface, a missing operator, or a lower layer that has not passed |
| `PASS` | the real procedure ran on real hardware and satisfied its acceptance criteria |
| `FAIL` | the procedure ran and the hardware did not satisfy it |
| `ERROR` | the framework itself broke, or the test made no observation at all |
| `ABORTED` | Ctrl+C, or the operator answered ABORT |

**`PASS` requires hardware evidence, mechanically.** `TestResult`
refuses to be constructed with `PASS` and a non-hardware evidence class,
so a dry run and a framework self-test cannot produce one — it is a type
error rather than a convention somebody has to remember. A self-test run
that exercises a success path reports `SKIPPED`, with the reason "these
checks passed against a fake transport; this says nothing about the
hardware".

A campaign verdict is pessimistic: any `FAIL` makes it `FAIL`, and any
unrun test makes it `INCOMPLETE`. **99 passes and one unexplained
failure is not a `PASS`** — it is an intermittent fault with a
hundred-iteration sample, and every repeated campaign reports the first
failing iteration, because "failed at 3" and "failed at 4,987" are
different faults with the same failure count.

---

## Evidence

Every real run creates its own directory:

```text
artifacts/HW-20260826-141233-EXECUTE/
├── run_manifest.json     mode, evidence class, git commit, host, profile
├── events.jsonl          one JSON object per event, flushed as it happens
├── measurements.csv      the numbers, for a spreadsheet or a plot
├── summary.json          every result, machine-readable
├── summary.md            the same for a human
├── operator_notes.md     what the operator observed, in their words
├── raw_serial.log        raw wire text, when any was captured
└── defects/HW-SERVO-001.md
```

The mode is in the **directory name**, not only in a field inside it,
because evidence gets copied and pasted into reports and the first thing
anybody sees is the folder.

`events.jsonl` is flushed after every line. A run killed by a power cut,
a Ctrl+C or a kernel oops leaves behind everything that happened up to
that moment — partial evidence is the only kind an interrupted endurance
run can produce, and it is worth having.

Nothing under `artifacts/` is committed.

---

## Operator-assisted tests

Some things cannot be read off a serial port. Whether the carousel
physically turned 180 degrees is not knowable from the wire — that is
the entire content of H-002 — so the framework asks a human and records
the answer as an answer:

- every operator input is timestamped and written to the evidence;
- every input is validated (`about 180ish` is not an angle);
- `UNKNOWN` is always an acceptable answer and becomes `None`, never a
  fabricated zero;
- checks made from a human observation are marked `OPERATOR`, so a
  reader can always tell them from a measurement;
- `ABORT` is accepted at every prompt;
- in `--non-interactive` mode nothing is asked and **nothing is
  assumed** — the test becomes `BLOCKED`.

---

## Safety

The default invocation performs no hardware action. Beyond that, each
class asks its own question, once per run:

`READ_ONLY` · `COMMUNICATION` · `MOTION` · `ILLUMINATION` ·
`MANUAL_DISCONNECT` · `RESET` · `POWER_CYCLE` · `FAULT_INJECTION` ·
`ENDURANCE` · `FULL_SYSTEM`

Everything from `MOTION` upward needs a second confirmation on top of
`--confirm-hardware`, because "yes, the board is connected" and "yes,
the mechanism is clear and nothing is loaded" are different statements.

Endurance tests are off by default, need explicit bounded iteration
counts, and reject zero, negative, non-integer and over-ceiling values.

Fault injection introduces one controlled fault at a time — a cable, a
connector, a power switch. **Nothing in this campaign asks for an
electrical short, a reversed polarity, an overvoltage or a deliberate
brownout**; those damage hardware and prove nothing that pulling a
connector does not. An offline test scans every registered test's text
to keep it that way.

After uncertain movement or a lost link, **the carousel position is
UNKNOWN and a re-sync is required**. A reset or a power cycle does not
preserve confidence in a physical position, and B9 exists partly to
prove the firmware agrees. Cleanup tries to leave the illumination off
and to release the port; when it cannot confirm either, it records
`cleanup: {"confirmed": false}` with the reason rather than claiming
success.

**Never hide a failure by widening a tolerance, a timeout or a retry
count.** `ST3215_POSITION_TOLERANCE` is not touched by any test here.
HW-B4-003 measures the real closing-error distribution; any change to
that constant belongs in a commit, argued from those numbers, with the
run id attached.

---

## Interruption and cleanup

Ctrl+C anywhere — inside a body, inside a prompt, between tests —
produces an `ABORTED` result for the running test, runs its cleanup,
writes the summary and stops. Every test with a cleanup handler gets it
run after a pass, a failure, an exception and an abort. A cleanup that
throws is recorded as unconfirmed and never overwrites the body's
verdict: a test that failed and then cleaned up badly failed for the
reason it failed.

---

## Reporting a hardware defect

Failures get a persistent identifier from the test's own family, so a
defect can be referred to across runs:

`HW-SER-nnn` · `HW-USB-nnn` · `HW-SERVO-nnn` · `HW-CAR-nnn` ·
`HW-SENSOR-nnn` · `HW-INT-nnn` · `HW-MISSION-nnn`

Each is written to `defects/` with observed behaviour, expected
behaviour, reproduction steps, the evidence, the suspected layer, and
empty sections for root cause, fix, verification and regression test.
An empty "root cause" is a true statement about a fresh defect; fill it
in as the work happens, and add a regression test to `Tests/software`
when the cause turns out to be reachable there.

---

## Resuming after a failure

```bash
python3 firmware/Tests/hardware/run_hardware_tests.py --resume HW-20260826-141233-EXECUTE --run-campaign B4 --confirm-hardware --profile firmware/Tests/hardware/configuration/my-bench.json
```

`--resume` skips only tests that actually **passed on hardware** in the
named run. Fix the fault first: a resumed run that steps over a failure
is a run that has not been done.

---

## Layer gates

Layer *N+1* is not valid evidence while layer *N* is unresolved, so the
gates are enforced rather than documented. `B5` is gated by `B3` because
slot-addressed results mean nothing while the encoder and the mechanism
disagree; `B12` is gated all the way down to `B0`.

Only a **hardware** `PASS` opens a gate. Dry runs and self-tests write
nothing to the ledger.

The override exists for deliberate out-of-order diagnosis and costs
three things: `--expert-override`, a written `--override-reason`, and an
interactive confirmation. It is recorded permanently in the result and
in the event log, because an override that is not visible in the
evidence turns a diagnostic detour into a claim about the hardware.

---

## When production code changes

The framework reads the production system rather than describing it: the
firmware command table is parsed out of `protocol.py`, the PC command
surface is introspected from `SerialLink`, the constants come from
`config.py`, and the workflow screens are parsed out of the workflow
package. So a rename shows up as a **capability that has gone missing**
and the affected tests turn `BLOCKED` with the name in the reason —
rather than as a mysterious failure at the bench with a rover on the
field.

After any production change, run:

```bash
python3 firmware/Tests/hardware/offline_tests/run_offline.py
```

and re-read `--capabilities`. If a capability that used to be available
is now missing, the campaign that depended on it needs re-reading before
it is re-run.

---

## The thirteen tests that are BLOCKED today

None is blocked on a gap nobody can close. Every one names a thing you
can supply.

| Missing | Tests | How to unblock |
| --- | --- | --- |
| the test-side diagnostic agent | `HW-B2-006` `HW-B2-008` `HW-B2-011` `HW-B3-004` `HW-B6-001` | deploy it per [test_side_firmware/DEPLOYMENT.md](test_side_firmware/DEPLOYMENT.md) |
| `unit.module_id` | `HW-B0-006` | name the physical module in the bench profile |
| `instruments.multimeter` | `HW-B0-008` `HW-B4-008` `HW-B7-012` | declare it with model, serial and calibration date |
| `instruments.oscilloscope` | `HW-B0-010` | the same |
| `instruments.thermal_probe` | `HW-B11-007` | the same |
| `fixtures.representative_load` | `HW-B4-007` `HW-B5-007` | a bounded, documented mass — never a jam fixture |

**The competition firmware was not changed to unblock anything.** The
three original blockers needed raw servo bytes and an on-demand I2C
scan; adding either to a build that can reach a competition is a worse
defect than the gap it fills. They are provided instead by a read-only,
whitelisted, manually deployed agent under `test_side_firmware/`, which
never runs at boot and has no movement command at all.

`--capabilities` prints the full reason and recommendation for each.

---

## Related documents

- `PLAN.md` — the B0 to B12 order and the full traceability table
- `HARDWARE_VERIFICATION_PLAN.md` — the H-001 to H-008 assumptions and
  what would falsify each
- `PHASE_B_CAMPAIGNS.md` — the earlier prose procedures, and the owner
  of every `HARDWARE_ONLY` exception handler
- `Documentation/OPERATIONS.md` — running the instrument
- `../software/SOFTWARE_FREEZE.md` — the frozen software baseline this
  campaign sits on top of

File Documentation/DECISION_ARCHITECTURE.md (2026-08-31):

# Decision architecture — audit and implementation plan

The system is being split into six layers so that FREYA can learn from
verified measurements **without ever rewriting a measured reference
spectrum**.

```text
1. physical acquisition            ESP32/
2. deterministic processing        Science/     -> EvidencePackage
3. immutable measured references   BD/ DB1, DB2
4. learning / experience           BD/ decision_learning.sqlite3
5. decision model                  Science/    -> Decision
6. explainable conclusion          PC/
```

---

## Part 1 — Audit of what already exists

Done before any code was written. The conclusion is that a large part of
layers 2 and 5 already exist but are **fused together** in two modules,
and that almost nothing of layer 4 exists.

### What exists and is reused as-is

| Concern | Where | Verdict |
|---|---|---|
| 18 channels, 2 feature spaces, projection | `BD/channels.py` | reuse, extended with `combine_illuminations` |
| DB1/DB2/DB3 loading, validation, status | `BD/registry.py` | reuse unchanged |
| Material taxonomy: `material_id`, `canonical_name`, `chemical_formula`, `material_class`, `aliases` | inside `DB1.json` / `DB3.json` | **already exists** — no new taxonomy invented, see §51 |
| Calibration library and activation | `BD/calibrations.py` | reuse, schema extended |
| Sample archive | `BD/samples.py` | reuse; learning DB references it by id + hash |
| Repeat aggregation, CV, outlier rejection | `Science/aggregation.py` | reuse |
| cosine / RMSE / MAE / SAM / Pearson | `Science/metrics.py` | reuse the primitives; ranking replaced |
| QC checks | `Science/quality.py` | reuse the checks; **verdict semantics split** |
| NNLS mixture | `Science/mixture.py` | reuse, demoted to secondary evidence |
| Cross-database inference, consensus, confidence | `Science/inference.py` | **moves to `Science/`** |

### What is wrong today, evidenced by the operator's own session

Twelve known reference materials were measured on 2026-08-17. Under the
current pipeline:

- **6 of 12 produced no identification at all.** `quality.check_reflectance`
  returned FAIL because reflectance exceeded 1.0, and a FAIL suppresses
  classification entirely. But the RAW spectra are perfectly good: the
  samples are simply brighter than the white target that was used, so the
  *normalization* is ill-conditioned, not the *measurement*. This is
  exactly §11 — `HARDWARE_QC_FAIL` and `NORMALIZATION_WARNING` are
  different things and were being conflated.
- **UV normalization is meaningless above ~610 nm and nothing says so.**
  The UV white reference reads 1.6–4.3 counts on K–W against a dark of 0,
  so R_uv lands on values like 0.333 or 2.727 — quantization of a
  denominator of two counts. RAW is valid; normalized is not. §12.
- **Rank aggregation destroys the evidence.** Activated Carbon scored
  RMSE 0.0088 against a runner-up at 0.17 — a twentyfold separation — and
  that arrived at the decision layer as "rank 1", indistinguishable from
  a winner that led by 0.001. §25.
- **One prediction was simply wrong** (Iron(II) Sulfate measured, Kaolin
  reported) and the system had nowhere to record that fact. §27.
- `Science/analysis.py` reaches a semantic conclusion
  (`best_match`, `automatic_conclusion`), which §10 forbids.

### Layer rule, unchanged and extended

```text
BD -> Science       FORBIDDEN
BD -> Science.decision      FORBIDDEN
Science -> BD       allowed
Science.decision -> BD      allowed
Science.decision -> Science  allowed
Science -> Science.decision  FORBIDDEN
```

`Tests/test_architecture.py` enforces all six.

---

## Part 2 — Implementation stages

Each stage lands with its own tests and leaves the tree green.

### Stage A1 — BD: identity, profiles, learning store

- `BD/taxonomy.py` — reads the material identity that **already exists**
  in DB1/DB3. Resolves display names, ids, aliases (including the Czech
  names already stored) and families. Invents nothing.
- `BD/acquisition_profiles.py`, stored inside `BD/calibration/calibration.json` — HOW a
  measurement was made, separate from the calibration (what the reference
  read) and from the measurement (what the sample read). §40.
- `BD/decision_learning.py` — SQLite. Observations, ground truth with
  provenance, per-model predictions, class statistics, training runs.
  Historical predictions are immutable; a new model version writes a new
  row. §5, §6, §46.

### Stage A2 — Science: evidence, not conclusions

- `preprocessing.py` — dark correction, reference normalization,
  unit-vector, SNV.
- `spectral_features.py` — wavelength-aware first and second derivative,
  block energies, cross-illumination ratios and log-ratios.
- `channel_reliability.py` — per illumination x channel: `raw_valid`,
  `normalized_reliability`, `weight`, reasons. Raw validity and
  normalized validity are separate verdicts. §12.
- `distances.py` — six metrics, each with winner, runner-up, absolute and
  relative margin, and the score distribution. §14, §25.
- `class_distance.py` — nearest centroid, standardized Euclidean,
  shrinkage Mahalanobis, kNN. §15.
- `evidence.py` — assembles the versioned `EvidencePackage`. §42.

### Stage A3 — Science.decision: cold start

- `engine.py` — the hierarchical decision. §21, §22.
- `evidence_fusion.py` — magnitude-aware fusion, never equal rank sums.
- `hierarchy.py` — family before material.
- `unknown_detection.py` — out-of-distribution. §37.
- `reliability.py` — per-database, per-class reliability learned from
  verified history, falling back to the shipped priors. §26, §45.
- `explainability.py` — sentences built only from structured evidence. §44.
- `model_registry.py` + `models/registry.json` — one ACTIVE model. §48.
- `calibration_transfer.py` — staged, EXPERIMENTAL, off by default. §28.

### Stage A4 — seed the learning database

The twelve measurements of 2026-08-17 are imported as the first
`VERIFIED` observations, with their original raw spectra, the calibration
and profile in force, and the prediction the old pipeline made. Nothing
in DB1/DB2/DB3 is touched. §52.

### Stage A5 — PC integration and ground-truth capture. §58, §59.

### Stage A6 — old vs new comparison report. §65.

### Later phases

Phase C (nearest centroid, kNN, regularized LDA, PLS-DA, SVM) and Phase E
(affine / DS / PDS transfer) are scaffolded with their interfaces and
their validation harness, and are **not** trained on twelve observations.
The registry records them as `INSUFFICIENT_DATA` until the dataset can
support group-aware validation. §33, §62.

---

## Part 3 — What was built, and what it does

### The layers, as they now exist

```text
firmware/
├── Science/          deterministic mathematics -> EvidencePackage
│   ├── preprocessing.py       dark, normalize, unit, SNV, conditioning
│   ├── spectral_features.py   wavelength-aware derivatives, energies,
│   │                          cross-illumination ratios
│   ├── channel_reliability.py 54 verdicts: raw_valid vs normalized_valid
│   ├── distances.py           6 metrics + margins + absolute goodness
│   ├── class_distance.py      centroid, standardized, shrunk Mahalanobis, kNN
│   └── evidence.py            the versioned EvidencePackage
│
├── Science/         interpretation -> Decision
│   ├── engine.py              the hierarchy, four levels
│   ├── evidence_fusion.py     magnitude-aware, one vote per family
│   ├── hierarchy.py           family before material
│   ├── unknown_detection.py   OOD, counted not averaged
│   ├── reliability.py         measured where possible, declared where not
│   ├── class_models.py        distributions from verified observations
│   ├── explainability.py      sentences built only from evidence fields
│   ├── calibration_transfer.py staged, UNAVAILABLE until pairs exist
│   ├── model_registry.py      one ACTIVE model, activation is a decision
│   └── training/              import, datasets, group-aware CV, baselines
│
└── BD/
    ├── taxonomy.py            identity, read from DB1/DB3, never invented
    ├── acquisition_profiles.py HOW a measurement was made
    ├── decision_learning.py   the SQLite history
    └── data/
        ├── operator_aliases.json
        └── decision_learning/
            └── (the seed it was bootstrapped from lives with the
                 tooling, in research/training/data/, and its id and
                 hash are recorded in the database's own meta table)
            └── decision_learning.sqlite3  the working database
```

### The four rules, enforced by tests

| Rule | Where it is enforced | Test |
|---|---|---|
| A prediction is never ground truth | `add_ground_truth` refuses any source naming a model | `test_decision` §1 |
| A historical prediction is never rewritten | `add_prediction` refuses a duplicate (measurement, version) | `test_decision` §1 |
| A raw measurement is never edited | observations are insert-only and hashed | `test_decision` §1 |
| A decision never modifies a reference | no Science.decision module names a database file | `test_decision` §8, `test_architecture` §2c |

### Old pipeline versus new, on the twelve verified measurements

Every one of the twelve is a labelled laboratory material, so the truth
is known for all of them.

| | old pipeline | Decision Model V001 |
|---|---|---|
| named the right material | 2 | 2 |
| **named the wrong material** | **3** | **0** |
| suppressed entirely by QC | 7 | 0 |
| family correct | — | 1 |
| family wrong | — | 3 |
| ambiguous set containing the truth | — | 1 |
| ambiguous set missing it | — | 1 |
| UNKNOWN | — | 4 |

The headline is the second row. The old pipeline named three materials
confidently and wrongly; the new one names none. It also stopped throwing
away seven good measurements: their raw counts were always valid, and
what had failed was the reference division.

It is not uniformly better. Three family-level answers are wrong, which
is a real failure even though it is a less dangerous one than a confident
wrong name. Both remaining problems have the same cause and the same fix:

1. **One independent measurement per material.** Every class has a
   centroid and no scatter, so "is this sample typical of Talc?" cannot
   be asked. A second independent measurement of each material - removed,
   repacked, remeasured - unlocks class distance, standardized distance
   and, at six per class, Mahalanobis.
2. **The white reference does not describe the samples.** Six of the
   twelve exceed it, one by 53%. The reference target is measured at a
   different effective geometry from the samples. Re-taking the
   calibration with the target in the exact sample position would repair
   the normalization for half the dataset.

### What was NOT done, deliberately

- **No threshold was tuned against these twelve.** Two changes were made
  after seeing results, and both were structural faults found by unit
  tests, not adjustments to make the samples score better: a
  floating-point comparison that dropped the runner-up from its own
  ambiguity band, and a corroboration rule that no chemical could ever
  satisfy because DB3 contains no chemicals. Every threshold remains
  labelled `PROVISIONAL_UNVALIDATED`.
- **No classifier was trained.** `cross_validation.feasibility` reports
  that twelve classes with one group each cannot support leave-one-out
  validation - holding a class out removes it from training entirely, so
  the score would measure the dataset rather than the model. LDA, PLS-DA
  and SVM are named, their prerequisites stated, and left unimplemented.
- **No calibration transfer was fitted.** Zero paired materials exist:
  DB1's session and this one share names but no measurement pairs.
  `calibration_transfer.build` returns UNAVAILABLE with the count.

### Running it

```bash
py -m Science.decision.training.import_seed
```

```bash
py -m Science.decision.training.import_seed --apply
```

```bash
py -m Science.decision.training.validate --record --detail
```

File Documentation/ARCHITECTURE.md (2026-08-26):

# Architecture

The system in one picture, and the rules that keep it that shape.

```
                         OPERATOR
                            │
                            ▼
                            PC
                 workflow / orchestration
                      /              \
                     /                \
                    ▼                  ▼
                 ESP32              Science
             hardware + RAW       scientific math
                    │                  │
                    │                  ▼
                    │                  BD
                    │        calibration / DB1 / DB2 /
                    │        DB3 / training / samples
                    │                  ▲
                    └── Measurement ───┘
```

Five questions, five answers:

| Question | Answer |
|---|---|
| Who controls physical hardware? | **ESP32** |
| Who controls operator workflow? | **PC** |
| Who performs scientific processing? | **Science** |
| Who produces the final classification? | **Decision Model, inside Science** |
| Where are calibration, references and completed results stored? | **BD** |
| Who generates the final report? | **Not this project.** |

---

## 1. The directory layout

```
firmware/
├── ESP32/      the hardware controller, MicroPython, flat
├── PC/         operator workflow and orchestration
├── Science/    every scientific formula and the Decision Model
├── BD/         calibration, DB1/DB2/DB3, training data, records
├── Tests/      the software campaign, and the hardware backlog
├── tools/      device.py — deploy and verify the ESP32
└── research/   non-production: experiments, ERC planning, training
```

`ESP32/`, `PC/`, `Science/` and `BD/` are the production domains.
`Tests/`, `tools/` and `research/` support them. There is nothing else.

---

## 2. Dependency direction

Allowed:

```
PC ──────► ESP32       JSON over USB, nothing else
PC ──────► Science
PC ──────► BD
Science ─► BD          calibration and reference databases
Tests ───► everything
tools ───► PC/serial_link.py
```

Forbidden, and each enforced by a check in `Tests/software/static/test_architecture.py`:

```
ESP32 ──► Science, BD, PC        the device cannot see a database
Science ► a serial port, a servo, a carousel, the operator
BD ─────► Science                storage must be readable without
                                 the layer that interprets it
BD ─────► hardware
production ► research            an unvalidated experiment must never
                                 reach a reported conclusion
```

`BD/channels.py` is the one thing every layer imports. It holds the
18 channel letters, their wavelengths and the feature-space
identifiers — the *schema* of the stored data, not its meaning. BD has
to be able to check the shape of a record without depending on Science.

---

## 3. ESP32 — hardware, and only hardware

Seven files, flat, no packages:

| File | Responsibility |
|---|---|
| `boot.py` | Deliberately empty. Explains why. |
| `main.py` | Build the runtime state, build the protocol, serve. |
| `config.py` | Every hardware constant, once. |
| `sensor.py` | AS7265x driver and the one sensor lifecycle. |
| `servo.py` | ST3215 wire protocol, driver and connection gate. |
| `carousel.py` | Slot geometry and logical position. |
| `protocol.py` | Newline-JSON framing, dispatch, and all 25 commands. |

The device never learns what a material is. No cosine, no
normalization, no database, no decision.

### Protocol first

Nothing between reset and the serving loop touches a peripheral — no
I²C transaction, no UART, no settling delay, no retry loop. A board
that cannot be reached cannot be diagnosed.

```
RESET → boot.py → main.py → JSON protocol ONLINE
                              │
                              ├── sensor:   NOT_INITIALIZED → READY | UNAVAILABLE
                              ├── servo:    not connected until asked
                              └── carousel: position invalid until declared
```

Measured on hardware: the board answers `ping` **3 ms** after boot. The
3-second sensor settling delay is still enforced, but it is paid by the
first command that actually needs the sensor, not by the protocol.

Every one of those degraded states leaves `ping`, `get_status` and the
diagnostics answering — because those are how an operator finds out
which of them is the problem.

### Carousel geometry

```
4 slots, 90° apart
loader and scanner exactly 180° apart = 2 slots

    load_slot = ((scan_slot - 1 + 2) % 4) + 1
```

Its own inverse: Slot 1 at the loader necessarily means Slot 3 at the
scanner. The mapping, the slot count and the offset all come from
`config.py`, and the carousel asserts their consistency at construction.

**Logical geometry is not actuator calibration.** One slot is 90°,
always, even where the real mechanism needs a small correction. The
correction is a mechanical calibration; the 90° is a fact about the
carousel.

---

## 4. PC — workflow and orchestration

```
PC/
├── rover_science_client.py   entry point: parse, open one port, hand over
├── serial_link.py            the ONE serial owner
└── workflow/
    ├── prompts.py            the only input() in the project
    ├── display.py            results → tables
    ├── session.py            link, stores, loaded science layer
    ├── calibration.py        making and choosing a calibration
    ├── carousel.py           servo setup, alignment, diagnostics
    ├── measure.py            the measurement sequence
    ├── records.py            the archive, and ground truth
    └── screen.py             the main screen and the menu loop
```

The PC implements no scientific formula. Every number on screen was
computed by Science.

### Exactly one serial owner

`serial_link.py` is the only module in the project that imports
pyserial. Two facts in it were measured on the bench, not assumed:

- **Opening the port resets the board.** pySerial asserts DTR and RTS
  on open, which drives the auto-reset circuit. Setting both low
  *before* `open()` leaves the firmware running.
- **A hardware reset is an RTS pulse with DTR low**, producing
  `boot:0x13 (SPI_FAST_FLASH_BOOT)`. Driving both lines instead lands
  in `boot:0x3 (DOWNLOAD_BOOT)`, where the firmware never runs.

Failures carry a code, because "the module did not answer" has eight
causes needing eight different actions:

```
PORT_NOT_FOUND      no such port
PORT_BUSY           it exists and something else holds it
PORT_DENIED         it exists, nothing holds it, and this account may
                    not open it - Linux serial group membership
PORT_OPEN_FAILED    it exists, is free, and would not open
PORT_LOST           it disappeared mid-request
PORT_CLOSED         the link is closed, usually because it was lost.
                    Every hardware method answers this rather than
                    raising - see below
PROTOCOL_TIMEOUT    the port opened; nothing answered
DEVICE_AT_REPL      MicroPython is at >>>, not serving
MALFORMED_RESPONSE  something answered and it was not a frame
INVALID_REQUEST     we were asked to send something that is not legal
                    JSON, and refused before sending it
DEVICE_ERROR        the firmware answered "ok": false
```

**A closed link is an operational condition, not a programming error.**
Every method on `SerialLink` answers a closed link with a `PORT_CLOSED`
LinkError. It used to raise a bare `RuntimeError`, and on the Linux
bench that ended the application: `/dev/ttyUSB0` disappeared, the link
correctly closed itself, and the next status refresh from the menu loop
was an uncaught traceback. 39 places in the PC layer catch `LinkError`;
exactly one caught `RuntimeError`.

**Matching an answer to its question** needs three things to agree: the
request id, the presence of `ok`, and the command name. Request ids are
`<24 random bits>-<counter>`, because two earlier designs collided
across sessions — a counter from 1, and a clock-seeded counter that
wrapped every 1000 seconds.

**A movement failure says what the mechanism did.** `NOT_STARTED`,
`MOVED` or `UNKNOWN` — never a bare "nothing moved", which an operator
standing at the rover acts on physically.

---

## 5. Science — the mathematics, and nothing else

```
Science/
├── channels via BD          the 18 bands and the feature spaces
├── preprocessing.py         dark, white, representations, repeats
├── quality.py               measurement quality and channel reliability
├── features.py              derivatives, ratios, cross-illumination
├── metrics.py               cosine, SAM, correlation, distances, ranking
├── comparison.py            distance to a material CLASS
├── calibration.py           building and validating a calibration
├── taxonomy.py              material identity and family
├── class_models.py          class statistics from verified history
├── model_registry.py        which model is ACTIVE, and why
├── decision.py              the Decision Model
└── pipeline.py              evidence, and the one entry point
```

Deterministic and hardware-independent:

```python
run = pipeline.analyze(measurement, calibration, registry, ...)
```

Given the same Measurement, calibration and databases it returns the
same answer. It opens no port, moves nothing, asks nothing, writes
nothing.

### The order

```
RAW Measurement
  → schema / acquisition validation
  → calibration selection
  → dark correction
  → white normalization
  → quality evaluation
  → feature extraction
  → DB1, DB2, DB3, each INDEPENDENTLY
  → individual metric evidence
  → distance to reference, distance to class
  → cross-method and cross-database agreement
  → Decision Model
  → AnalysisRun
```

Each stage records its own status. A database that will not load, an
absent class snapshot or a model that raises leaves everything the
earlier stages produced intact:

```
analysis_status = PARTIAL
DB1  OK      evidence kept
DB2  OK      evidence kept
DB3  FAILED  reason recorded
```

### One comparison, not two

`pipeline.build()` compares the measurement against each database once
and keeps the three results apart. The Decision Model is the only thing
allowed to combine them. There is deliberately no second per-database
comparison reaching its own consensus — that arrangement produced two
answers in one record with nothing to say which was right.

### Provenance classes

Never blurred:

| Class | Example |
|---|---|
| `MEASURED` | an AS7265x raw channel; DB1 and DB2 |
| `CALCULATED` | dark-corrected, normalized, a cosine, a 54-vector |
| `REFERENCE` | a published external spectrum, as published |
| `DERIVED_REFERENCE` | that spectrum projected onto our bands; DB3 |
| `MODEL_INFERENCE` | a Decision Model conclusion |

---

## 6. BD — the authoritative record store

```
BD/
├── calibration/   dark and white references, and the conditions
├── DB1/           MEASURED here, 18 channels, 23 materials, legacy
├── DB2/           MEASURED here, 54 features (WHITE/UV/IR)
├── DB3/           DERIVED_REFERENCE, 84 external spectra projected
├── training/      labelled records and the decision history, OFFLINE only
├── models/        validated model artifacts and the registry
└── samples/       completed Sample records — the run's only output
```

One directory per thing it answers a question about. Two of these are
read-only scientific evidence and one is the only thing the system
writes.

### The three databases are never pooled

A cosine of 0.97 against DB1 means *"this looks like something we
measured here"*. The same number against DB3 means *"this looks like a
laboratory spectrum, after modelling our sensor"*. They are compared
separately, reported separately, and only then checked for agreement.

DB1 is compared **only** against the frozen legacy calibration it was
built with. Normalizing it against today's calibration would silently
change what every stored number means.

---

## 7. The record model

```
Sample                      the physical material
│
├── metadata
│
└── Measurements[]          one completed physical acquisition each
      │
      ├── RAW, grouped by illumination     ← written once, never again
      ├── acquisition metadata
      ├── acquisition_status
      ├── calibration_id
      │
      └── AnalysisRuns[]    one interpretation each
            ├── preprocessing
            ├── quality
            ├── metrics
            ├── DB1 / DB2 / DB3, separately
            ├── reference distances
            ├── class distances
            ├── method and database agreement
            ├── Decision Model result
            └── versions and provenance
```

Three layers, never collapsed. A store where `sample.measurement` is
singular cannot be taught repeatability afterwards without rewriting
every record ever saved.

**RAW is immutable.** Once a successful Measurement is persisted its
`raw` block is never written again — not by normalization, a new
calibration, a new Science version or an edit. There is no API to
modify a Measurement; the only way to add data is to add a record.

**RAW is saved before Science runs.** The measurement flow is

```
acquire → PERSIST RAW → analyse → persist the AnalysisRun
```

so a database that will not load, an exception in the pipeline or a
model that raises costs an *analysis*, not an *experiment*.

**A failed acquisition is not poor quality.** It is stored with
`acquisition_status = FAILED` and no `raw` key at all — deliberately
not a successful measurement full of zeros, which cannot be told apart
from a genuinely dark reading.

---

## 8. Where the project stops

```
FREYA
  ↓
complete structured Sample Result
  ↓
BD/samples/
  ↓
──────── PROJECT BOUNDARY ────────
  ↓
external AI or human workflow
  ↓
report / document / prose
```

The system produces a structured, versioned, traceable scientific
record. It does not produce prose, PDFs, mission reports or competition
documents, and production Science contains nothing that could.

The record has to carry enough evidence for someone outside to write
that report without guessing: which pipeline, which model, which
library versions, which calibration, what each database said on its
own, where the methods disagreed, and what was refused.

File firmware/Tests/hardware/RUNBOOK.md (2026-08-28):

# Real-hardware runbook

What to do, in order, on the day the module is on the bench.

> **Mostly not executed.** 24 of the 107 tests have real hardware
> evidence from 2026-08-27 (17 PASS, the rest BLOCKED on a human
> observation). Everything from B3 onward is `NOT_RUN`. This is the
> procedure, not a record.
>
> Two tests carry `ever_failed` in the ledger — **HW-B1-009, HW-B2-004** — meaning they
> failed on hardware before later passing. That history is deliberate
> and must not be cleared: HW-B1-009 is a real transport anomaly
> (one damaged frame in ~800 requests) and HW-B2-004 failed for an
> adapter defect that is now fixed.

---

## 0. Day one, in order

The short sheet. Every phase below has a full section later; this is the
sequence, the pass condition and the stop condition, in the order you
will actually work.

**`<PORT>` is resolved once, in step B, and reused everywhere.**

| # | Do this | PASS when | STOP if |
| --- | --- | --- | --- |
| A | `git status` in the repo; confirm you are on the frozen tree | 29 modified, 9 untracked, HEAD `e2848f2` | anything else — restore from the checkpoint first |
| B | identify the device (below) | exactly one CP2102 `10C4:EA60` | zero or two matches — do not guess a `ttyUSB` number |
| C | `device.py status --port <PORT>` | filesystem matches the manifest | stale files present → `deploy --clean` |
| D | `device.py deploy --port <PORT> --clean` then `verify` | every SHA256 matches, and `RECEIPT PASS` | any mismatch — do not proceed to tests |
| E | **preflight** (below) | board answers, protocol 2, sensor + servo states as expected | no answer, or PROTOCOL MISMATCH → re-deploy |
| F | `--run-campaign B0` | environment and identity recorded | B0 FAIL — the bench is not what you think |
| G | `--run-campaign B1` | link qualified | transport FAIL → stop; everything above rides on it |
| H | `--run-campaign B2` | ID 1, STEP mode, pins as configured | mode ≠ 3, or no answer → servo/power, not software |
| I | `--run HW-B2-013` | the reported position changes by the commanded counts | it does not — H-002 has recurred; **stop, capture, do not change tolerance** |
| J | B3 → B4 → B5 | `HW-B3-006`, `HW-B3-008` pass first | either fails |
| K | B6, B7 | sensor qualified | AS7265X_NOT_FOUND recurs → sensor campaign, not carousel |
| L | B8: 180 out → WHITE → UV → IR → 180 back | one full transaction, sample home | any stage FAIL → recovery flow, capture evidence |
| M | repeat L ×10, then ×25 | closing error stays bounded | drift grows → stop, characterize |
| N | all four slots, 1→2→3→4→1 | every transition verified | wrap-around fails → geometry, not transport |
| O | B9 recovery | faults handled honestly | — |
| P | B10, B12 mission rehearsal | operator workflow end to end | — |

### B. Identify the device

```bash
ls -l /dev/serial/by-id/
```

Use the `by-id` path as `<PORT>`. It survives replugging; `ttyUSB2` does
not. If more than one CP2102 is present, `--list` the candidates and
decide deliberately — **the framework will refuse to guess, and so
should you.**

### E. Read-only preflight

```bash
python3 firmware/PC/rover_science_client.py --port <PORT> --preflight --save-evidence firmware/Tests/hardware/artifacts/
```

Moves nothing, writes no EPROM, changes no torque, runs no acquisition.
Reports board identity and protocol, sensor state, servo link/id/mode,
encoder, supply voltage and temperature, carousel validity, and the
transport counters. **Run this first, and again any time something goes
strange.**

### D. What the deployment receipt is for

A successful deploy writes
`firmware/Tests/hardware/artifacts/deployment-receipt.json` with the
SHA256 of each of the seven files it verified onto the device.

`verify` compares the device against **both** a fresh rebuild and that
receipt. The rebuild is only reproducible from the checkout that
deployed — mpy-cross embeds the source path — so if you ever see every
file mismatch at once, read the `RECEIPT` line: if it PASSES, the
firmware is the firmware you deployed and the rebuild is the thing
that is wrong.

### I. H-002 — resolved, and what to check if it comes back

**Resolved on hardware 2026-08-28.** In step servo mode register 56 is
the FOLLOWING ERROR, not a position, and the absolute position is
register 67 minus it. See `artifacts/H-002-evidence-20260828.md`.

Every movement record now carries both halves, and reading them in
order is the whole diagnosis:

| field | what it says |
| --- | --- |
| `trajectory_travelled` | how far the servo was TOLD to go. Open loop — it reaches the target under a stall too |
| `measured_travel` | how far the shaft actually went |
| `following_error` | how far the shaft is from the target now |
| `verification` | `VERIFIED`, `UNVERIFIED` or `FAILED` |

`trajectory_travelled` equal to the request while `measured_travel` is
near zero means the command ran and the MECHANISM did not follow —
a stall, a slipping coupling, an exhausted torque budget. Neither of
them advancing means the command never reached the servo — bus, power
or protocol.

**Do not** raise `ST3215_POSITION_TOLERANCE`, disable encoder
verification, or substitute `trajectory_travelled` for
`measured_travel`. The last of those would pass a carousel that never
turned, which is exactly what the trajectory register does under a
stall.

### I.1 The trajectory register runs out, and it does so in service

Register 67 accumulates NET one-directional travel and clamps at
**32766**. Past the clamp the servo will not move in either direction
and still reports a following error of about 2 — a movement that looks
verified and did not happen.

A carousel that takes the shortest path to each slot advances one slot
every time, so a run working through slots 1-2-3-4-1 turns a full
revolution every four samples and reaches the clamp after about thirty
slot advances. **This is routine.**

The driver folds the register back before it gets there: it passes
through position servo mode, which reseeds register 67 from the
absolute encoder, and it carries the logical carousel angle across
unchanged. Nothing moves. It writes EPROM, so it is counted —
`trajectory_reseeds` in the servo telemetry, beside
`trajectory_headroom`, which is how far there is left to go.

If you ever see `SERVO_TRAJECTORY_LIMIT`, the fold could not be made:
run the servo configuration command, then re-synchronize.

---

## 0.1 Degraded modes — what is still true

| Situation | Still trusted | Next safe action | Never |
| --- | --- | --- | --- |
| **Link lost** | nothing about the mechanism | re-open the port, `--preflight` | assume the carousel stayed put |
| **Servo OFFLINE** | sensor, link, records | sensor diagnostics, B6/B7 can still run | any carousel campaign |
| **Servo ONLINE, position UNKNOWN** | servo link, sensor, all records | look at the plate, then **re-sync** | re-send the failed movement |
| **Sensor UNAVAILABLE** | servo, carousel position | sensor diagnostics; the measure path re-probes and may recover it | moving a sample to chase a sensor fault |
| **Position UNVERIFIED** | the servo link, the records, and the position itself — it is believed, not proven | read the status again; the position is measurable, it just was not measured at the one moment it mattered | treating it as a mechanical failure, or re-syncing working hardware |
| **Return move failed** | the spectra — they are acquired and saved | re-sync, then continue | treating the record as a normal success |
| **PC client restarted** | everything in `BD/` — samples, measurements, learning | reconnect; the client re-reads all state from the firmware | trusting any remembered position |
| **ESP32 reset** | records on the PC | re-connect servo, re-sync | assuming position survived the reboot |

A campaign that fails now prints what failed, whether a test that could
move the mechanism was among them, and the exact `--resume` command.
`--resume` only **skips** tests that already passed on hardware; it
never replays one.

---

## 1. Bench equipment

| | Needed for | Without it |
| --- | --- | --- |
| The module: ESP32, ST3215, AS7265x, carousel | everything | nothing runs |
| USB cable to the Linux main computer | everything | nothing runs |
| External servo supply | any movement | B2 onward blocked |
| **Protractor or angle gauge** | **H-002 (B3)** | the most important campaign cannot run |
| Reference mark on the plate | B3, B5, B11 | rotation drift unmeasurable |
| Multimeter | B0-008, B4-008, B7-012 | those tests report BLOCKED |
| Oscilloscope or logic analyzer | B0-010 | signal integrity BLOCKED |
| Thermal probe | B11-007 | thermal baseline BLOCKED |
| Bounded representative load | B4-007, B5-007 | loaded characterization BLOCKED |
| Stable reflectance target | B7 spectral stability | reduced |
| Camera or photodiode that sees IR | B7-006 | IR observation is UNKNOWN |
| Ability to detach the plate from the shaft | B3 shaft-vs-plate | coupling slip not isolable |

A BLOCKED test is not a failure. It is the framework saying which
instrument it needs, by name, before you power anything.

---

## 2. Pre-power checklist

Do all of this **before** applying power.

- [ ] Supply polarity checked at the connector.
- [ ] Connector identity confirmed — nothing is one pin out.
- [ ] ESP32 and servo supply share a common ground.
- [ ] Servo current does **not** pass through the sensor PCB.
- [ ] Power can be removed without reaching past anything that moves.
- [ ] The mechanism can be stopped by hand or by cutting power.
- [ ] Carousel is empty and free to turn a full revolution.
- [ ] Nobody is looking into the sensor head (UV will be switched on).
- [ ] A reference mark exists on the plate.

`HW-B0-005` asks each of these again, one at a time, and records the
answers. Answer them honestly; a confirmation you did not actually check
is worse than a BLOCKED test.

**Never** short a rail, reverse polarity, overvolt anything, force a
brownout, stall the servo, hot-plug what is not designed for it, or
defeat a fuse. No test in this campaign asks for any of that, and if one
appears to, stop and read it again.

---

## 3. Create the bench profile

```bash
cp firmware/Tests/hardware/configuration/profile.example.json firmware/Tests/hardware/configuration/my-bench.json
```

The example is a template and **thirteen tests are BLOCKED until it is
filled in**. Each names the field it needs:

| Field | Unblocks |
| --- | --- |
| `unit.module_id` | `HW-B0-006` |
| `instruments.multimeter` | `HW-B0-008`, `HW-B4-008`, `HW-B7-012` |
| `instruments.oscilloscope` | `HW-B0-010` |
| `instruments.thermal_probe` | `HW-B11-007` |
| `fixtures.representative_load` | `HW-B4-007`, `HW-B5-007` |
| `diagnostic_firmware.deployed` | `HW-B2-006`, `HW-B2-008`, `HW-B2-011`, `HW-B3-004`, `HW-B6-001` |

An instrument with no calibration date is refused by the profile
validator.

---

## 4. Identify the hardware unit

A prerequisite PASS earned on one module says **nothing** about another,
and the layer gates check that by fingerprint. So:

```bash
python3 firmware/Tests/hardware/run_hardware_tests.py --run HW-B0-004 --confirm-hardware --port /dev/ttyUSB0
```

That enumerates and opens nothing. Read `usb_serial_number` out of the
run's `measurements.csv`, put it in `my-bench.json` along with
`unit.module_id`, and use `--profile` from then on. After this the
campaign never needs to be told a device name again and **cannot open
the wrong board**.

---

## 5. Production versus diagnostic firmware

Run everything you can on the **competition firmware**. Only five tests
need the diagnostic agent, and it is deployed for a diagnostic session
and removed afterwards.

Before deploying it, record the production firmware hash. Then follow
`test_side_firmware/DEPLOYMENT.md` exactly, verify with `HW-B2-011`, and
restore with `HW-B2-012`.

> **Every prerequisite PASS earned while the agent was deployed is void**
> for a production run. The run fingerprint includes the diagnostic
> firmware, so the gate will refuse them — by design. Re-run what
> matters on the restored firmware.

---

## 6. Execution order

```bash
python3 firmware/Tests/hardware/run_hardware_tests.py --profile firmware/Tests/hardware/configuration/my-bench.json --run-campaign B0 --confirm-hardware
```

Then, in this order:

| Step | Campaign | Why here |
| --- | --- | --- |
| 1 | **B0** | inventory. Nothing connected, nothing opened. |
| 2 | **B1** | the link, measured on its own terms. |
| 3 | **B2** | the servo answers, and is the servo we think it is. |
| 4 | **B3** | **H-002.** The most important campaign. |
| 5 | **B6, B7** | the sensor — *in parallel, not blocked by H-002*. |
| 6 | **B4** | repeatability; the measurement that sets the tolerance. |
| 7 | **B5** | the carousel, once the encoder is trustworthy. |
| 8 | **B8** | the whole transaction, including the RF-001 regression. |
| 9 | **B9** | take things away and see what is admitted. |
| 10 | **B10** | a human, the real client, the real archive. |
| 11 | **B11** | the long runs. |
| 12 | **B12** | the rehearsal. Never first. |

Replace `B0` with each campaign in turn. The gates enforce the order
anyway; this is what to type.

---

## 7. Stop conditions

**Stop the campaign and diagnose** if any of these happen:

- `HW-B2-002` reports the servo is not in STEP mode. That is H-002
  hypothesis 1 and everything above B2 is meaningless until it is
  settled.
- `HW-B2-004` shows a position that changes with nothing commanded. A
  read that is not stable at rest cannot measure a movement.
- `HW-B3-001` shows the encoder and the protractor disagreeing. **Do not
  proceed to B5.** The result names which hypotheses remain open.
- `HW-B8-002` reproduces RF-001. Every carousel result above B3 is
  invalid until it is explained.
- Any ESP32 reset during movement (`HW-B4-008`). That is a brownout and
  it will masquerade as a firmware fault in every later campaign.
- Any protected reference file hash changes (`HW-B10-005`). Stop
  immediately; that is the one kind of test failure that costs more than
  the bug it was looking for.
- An illuminator left on after a failure (`HW-B7-008`, `HW-B9-005`).

**Do not** widen a tolerance, a timeout or a retry count to get past any
of these.

---

## 8. H-002 first

B3 is the campaign the whole servo side waits on. Before running it:

1. `HW-B2-002` must show `mode_correct` true.
2. `HW-B2-004` must show a stable position at rest.
3. Have a protractor and a reference mark.
4. **Detach the plate from the output shaft if you can.** The test asks
   whether the *encoder* tracks the *shaft*; a coupling that slips is a
   separate hypothesis and the assembled mechanism cannot tell them
   apart. If you cannot detach it, say so when asked and measure the
   plate.

```bash
python3 firmware/Tests/hardware/run_hardware_tests.py --profile firmware/Tests/hardware/configuration/my-bench.json --describe HW-B3-001
```

Read that before starting. Then:

```bash
python3 firmware/Tests/hardware/run_hardware_tests.py --profile firmware/Tests/hardware/configuration/my-bench.json --run HW-B3-001 --confirm-hardware
```

Answer every angle and direction question honestly. **UNKNOWN is a
correct answer** and produces INCONCLUSIVE, which is worth far more than
a guess that produces a PASS.

---

## 9. Evidence

Every run writes its own directory under `artifacts/`. Nothing there is
committed.

**Back it up as soon as a campaign finishes**, before the next one:

```bash
cp -r firmware/Tests/hardware/artifacts/HW-<run-id> ~/freya-evidence/
```

A number quoted in a report with no run id behind it is an opinion; a
run id with no archived directory behind it is a broken reference.

---

## 10. When something fails

1. The result already carries a defect record under `defects/` with a
   persistent `HW-xxx-nnn` id, the observed and expected behaviour, and
   reproduction steps.
2. Fill in root cause, fix, verification and regression test as the work
   happens. An empty "root cause" is a true statement about a fresh
   defect.
3. If the cause turns out to be reachable in software, add a regression
   test to `Tests/software` — that is where it will be caught next time
   for free.
4. Fix it. Then re-run:

```bash
python3 firmware/Tests/hardware/run_hardware_tests.py --profile firmware/Tests/hardware/configuration/my-bench.json --resume HW-<run-id> --run-campaign B4 --confirm-hardware
```

`--resume` skips only tests that actually **passed on hardware** in that
run, and refuses a run whose fingerprint no longer matches.

---

## 11. What invalidates a previous PASS

The run fingerprint covers all of this. When any of it changes, the
affected prerequisites stop opening gates — automatically, not by
anyone remembering:

- the repository commit, or a dirty working tree;
- the production ESP32 firmware or its configuration;
- the PC client or the protocol;
- the bench profile;
- **the physical module, servo, sensor or carousel assembly**;
- the mechanical assembly revision — a re-coupled plate is a different
  mechanism as far as H-002 is concerned;
- the test-side diagnostic firmware, deployed or removed;
- the hardware framework itself.

If you rebuild the mechanism, bump `unit.carousel_assembly_revision`.
Everything that depended on the old one will correctly stop counting.

---

## 12. Restore production firmware

Before the module goes anywhere near a competition:

```bash
python3 -m mpremote connect <device> fs rm :diagnostic_agent.py
python3 firmware/tools/device.py --port <device> --deploy
python3 firmware/Tests/hardware/run_hardware_tests.py --profile firmware/Tests/hardware/configuration/my-bench.json --run HW-B2-012 --confirm-hardware
```

`HW-B2-012` verifies the production firmware answers, the diagnostic
protocol does not, and the profile no longer claims a deployment.

---

## 13. Command reference

Safe — these touch nothing:

```bash
python3 firmware/Tests/hardware/run_hardware_tests.py --list
```

```bash
python3 firmware/Tests/hardware/run_hardware_tests.py --capabilities
```

```bash
python3 firmware/Tests/hardware/run_hardware_tests.py --dry-run --all
```

```bash
python3 firmware/Tests/hardware/offline_tests/run_offline.py
```

Per campaign, with a profile and an explicit confirmation:

```bash
python3 firmware/Tests/hardware/run_hardware_tests.py --profile firmware/Tests/hardware/configuration/my-bench.json --run-campaign B1 --confirm-hardware
```

Endurance runs are off by default, need their own confirmation, and
refuse a sample size below their own qualification minimum — a smaller
run produces CHARACTERIZATION, never a qualification PASS.

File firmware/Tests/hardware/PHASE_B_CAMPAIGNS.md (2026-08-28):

# Phase B — executable campaigns

The companion to `HARDWARE_VERIFICATION_PLAN.md`. That file states the
assumptions; this one states what to do about them, in enough detail
that a result survives the session it was produced in.

**Nothing here has been run.** The hardware was disconnected throughout
Phase A.

> ## These procedures are now registered and executable
>
> `run_hardware_tests.py` carries all of them as 78 registered tests
> across B0–B12, with the layer gates enforced, the evidence written to
> a per-run directory, and the operator prompted rather than assumed.
> `PLAN.md` has the order and the traceability table; `README.md` has
> the status and the safe commands.
>
> The HW-numbers below map onto the registered ids:
>
> | Here | Registered as |
> | --- | --- |
> | HW-100 | `HW-B0-004` |
> | HW-101 | `HW-B1-002` |
> | HW-102 | `HW-B9-001` … `HW-B9-005` |
> | HW-200 | `HW-B2-001` |
> | HW-201, HW-202 | `HW-B2-003` |
> | HW-203 | `HW-B2-002` |
> | HW-204 | `HW-B3-001` |
> | HW-205 | `HW-B4-003` |
> | HW-206 | `HW-B5-004` |
> | HW-300 | `HW-B6-002` |
> | HW-301 | `HW-B7-004` |
> | HW-302 | `HW-B6-005` |
> | HW-303 | `HW-B7-004` |
> | HW-304 | `HW-B6-005`, `HW-B7-004` |
> | HW-305 | `HW-B7-005` |
> | HW-306 | `HW-B11-002` |
> | HW-400 | `HW-B5-003` |
> | HW-401 | `HW-B9-004` |
> | HW-402 | `HW-B5-006` |
>
> The `HARDWARE_ONLY` handler owners in the table below are unchanged;
> read the owner column against the mapping above.

---

## Every HARDWARE_ONLY handler has an owner

`audit/handler_coverage.py` classifies sixteen exception handlers as
`HARDWARE_ONLY`: the fakes speak the real register and packet
protocols, which is what makes them useful, and exactly why they cannot
produce a half-written register or a frame corrupted in one specific
byte.

Each is owned by a numbered test below. A handler with no owner is a
handler nobody will ever see run.

| Handler | Condition it guards | Owner |
| --- | --- | --- |
| `sensor.py:240` `except OSError` | an I2C write the bus NAKs | HW-301 |
| `sensor.py:657` `except SensorError` | a channel that will not read back | HW-303 |
| `sensor.py:672` `except Exception` | a float that will not unpack from four raw bytes | HW-303 |
| `sensor.py:732` `except Exception` | `I2C()` construction failing on real pins | HW-300 |
| `sensor.py:751` `except Exception` | bus description unavailable | HW-300 |
| `sensor.py:973` `except Exception` | a recovery attempt failing | HW-304 |
| `sensor.py:1013` `except SensorError` | first initialization failing from cold | HW-302 |
| `servo.py:476` `except ImportError` | no `machine.Pin` — CPython only | see note |
| `servo.py:753` `except AttributeError` | a UART with no `deinit` | HW-201 |
| `servo.py:1779` `except Exception` | a movement leg failing mid-sequence | HW-204 |
| `servo.py:1997` `except Exception` | a diagnostics read failing | HW-203 |
| `servo.py:2029` `except ServoError` | a register read failing during diagnostics | HW-203 |
| `servo.py:2087` `except ServoError` | a scan probe failing | HW-202 |
| `servo.py:2497` `except AttributeError` | a backend without the optional method | HW-201 |
| `servo.py:2651` `except Exception` | driver construction failing | HW-200 |
| `servo.py:2725` `except Exception` | a torque write failing | HW-205 |

**Note on `servo.py:476`.** It is the one entry that is not hardware at
all: it guards `from machine import Pin`, and it executes on *every*
CPython run of the suite, because there is no `machine` module there.
It is already covered, every time. It is listed only so the table has
no gaps.

---

## How every test is written

```
setup       what must be true before starting
procedure   exactly what to do
expected    what a pass looks like
failure     what a fail looks like, and what it means
capture     the data to keep, so the result survives the session
```

A test that does not say what to capture produces an opinion rather
than a measurement.

---

## 1. `mainpc_esp32` — before anything moves

### HW-100 — USB enumeration and stability

```
setup       ESP32 unplugged; a terminal on freya-1-comp
procedure   plug in; ls -l /dev/serial/by-id/; dmesg | tail -20
expected    one CP2102 node within 2 s, with a stable by-id name
failure     no node, or a name that changes between plugs. H-004 is
            then false, and --port must use the by-id path rather than
            ttyUSBn
capture     the by-id string, the ttyUSBn it points at, the dmesg lines
```

### HW-101 — opening the port does not reset the board

```
setup       firmware running; ping answering
procedure   open and close the port 1000 times, reading the console
            after each open, looking for rst: or boot:
expected    zero boot banners. H-008 holds
failure     any banner. Opening the client reboots the instrument: the
            DTR/RTS discipline in serial_link.open() does not work on
            this board, and the operator must re-sync after every start
capture     banner count, and the text of the first one if any
```

### HW-102 — the port disappears mid-command

```
setup       a measurement in progress
procedure   pull the USB at each point: before the request, during the
            write, while waiting for the answer, mid-response.
            Repeat with the cable pulled at the hub rather than at the
            board
expected    PORT_LOST every time; the client survives; every later
            command is PORT_CLOSED; connect + sync recovers
failure     any traceback, or a command that appears to succeed
capture     the errno in error.data["errno"] for each point
```

`LNX-001` and `LNX-002` simulate all 32 errno x entry-point
combinations. This is the test that says which of them the real
hardware actually produces.

---

## 2. `esp32_servo` — the RF-001 investigation

**Run this before any carousel campaign.** Until H-002 is settled, no
carousel result means anything.

### HW-200 — the driver comes up

```
setup       servo powered, bus wired as the config describes
procedure   connect_servo; read mode, ID, baud and limits from the
            servo registers themselves
expected    the values match ESP32/config.py
failure     a mismatch. The config describes a servo that is not
            fitted. Owns servo.py:2651
capture     every register value read
```

### HW-201 — the ECHO_ONLY fault

```
setup       servo powered
procedure   servo_bus_scan at every baud, both pin orders, IDs 1-10
expected    exactly one ID answers, at one baud, in one pin order
failure     ECHO_ONLY again. TX and RX are crossed and the scan is
            seeing its own transmission. Owns servo.py:753 and
            servo.py:2497
capture     the full scan report: every baud, every ID, both orders
```

**Resolved 2026-08-27.** `HW-B2-003` probed eight baud rates in both
pin orders and got exactly one answer: ID 1, 1 Mbps, pins **as
configured** (TX GPIO17 / RX GPIO16), status byte `0x00`. The earlier
"answers only with TX and RX exchanged" result was the ESP32 receiving
its own transmission through a UART2 TX signal that `deinit()` does not
detach; `servo.release_uart_pins()` now prevents it. The failure mode
above is kept because it is still the right thing to look for — but a
swapped-order answer today means the loopback has returned, not that
the wiring is backwards.

### HW-202 — a probe that fails mid-scan

```
setup       servo powered
procedure   start a bus scan, then disconnect the servo data line while
            it is running
expected    the scan completes and reports the failure per ID
failure     the scan raises, or reports a clean result for a bus that
            was cut. Owns servo.py:2087
capture     the report, and the moment the line was cut
```

### HW-203 — diagnostics against a servo that stops answering

```
setup       servo connected and answering
procedure   servo_diagnostics; then power the servo down and repeat
expected    the first succeeds; the second reports SERVO_UART_TIMEOUT
            and the client survives
failure     a traceback, or diagnostics reporting values from a servo
            with no power. Owns servo.py:1997 and servo.py:2029
capture     both reports, side by side
```

### HW-204 — H-002: does the encoder track the mechanism?

**The most important test in this document.**

```
setup       servo FREE - carousel detached - with a protractor on the
            output shaft
procedure   1. read the encoder
            2. command a 2048-count relative move
            3. read the encoder again
            4. measure the shaft angle with the protractor
            5. repeat 10 times, both directions
            6. reattach the carousel and repeat every step
expected    2048 counts = 180 degrees, and the encoder delta matches
            the commanded delta within the H-001 tolerance
failure     the bench event repeating: a visible 180 degrees with an
            encoder delta of about 2 counts. That would mean the
            encoder is not reporting shaft position, and every carousel
            decision the firmware makes is built on a number that does
            not describe the mechanism. Owns servo.py:1779
capture     a table of commanded counts, encoder before, encoder after
            and protractor degrees, for all 20 free runs and all 20
            attached runs. Photograph the protractor at least once
```

If the free-shaft runs are correct and the attached runs are not, the
difference is the reduction ratio, and H-005 is false.

### HW-205 — torque, and the position tolerance

```
setup       carousel attached, HW-204 settled
procedure   servo_torque off and on, reading the register back each
            time; then fifty identical slot movements, recording every
            position_error
expected    torque reads back as commanded; the errors cluster well
            inside 15 counts
failure     a torque write that does not read back owns servo.py:2725.
            Errors near or beyond 15 mean the H-001 constant is wrong
            and must be re-derived from this data rather than guessed
capture     all fifty position_error values, as a list
```

### HW-206 — backlash

```
setup       carousel attached
procedure   alternate load and scan 200 times; measure the accumulated
            offset at 0, 50, 100, 150 and 200
expected    no monotonic drift. H-006 holds
failure     drift. The carousel walks away from its origin over a
            competition day, invisibly, until a sample misses the
            scanner
capture     the five offsets and the protractor reading at each
```

---

## 3. `esp32_sensor`

### HW-300 — the bus comes up on real pins

```
setup       sensor wired per config
procedure   power on; sensor_test_raw
expected    I2C initializes, 0x49 answers, all three devices present
failure     I2C_INIT_FAILED. The pins in config are not the pins
            fitted. Owns sensor.py:732 and sensor.py:751
capture     the full stage list from the diagnostic
```

### HW-301 — an I2C write the bus refuses

```
setup       sensor running
procedure   short SDA to ground briefly during a configuration write
expected    I2C_WRITE_FAILED, named as such, and the client survives
failure     a silent success, or a traceback. Owns sensor.py:240
capture     the error frame, and what was shorted when
```

### HW-302 — cold initialization, fifty times

```
setup       sensor powered down
procedure   power on, sensor_test_raw, power off; 50 cycles
expected    50 successes; record how long each took
failure     any failure. Owns sensor.py:1013, and the first_init_error
            it records is the diagnosis
capture     50 durations and 50 outcomes
```

### HW-303 — a channel that will not read

```
setup       sensor running, acquisition in progress
procedure   disconnect the sensor connector mid-acquisition, at each of
            the three illuminations
expected    CHANNEL_READ_FAILED or INCOMPLETE_SPECTRUM; no partial
            spectrum stored; lamps off afterwards
failure     a spectrum containing values from before the disconnect.
            Owns sensor.py:657 and sensor.py:672
capture     the error frame, and the lamp state read back afterwards
```

### HW-304 — recovery, and its budget

```
setup       sensor running
procedure   500 consecutive measurements, watching recovery_count
expected    recovery_count stays at 0, or rises while the measurements
            keep succeeding
failure     SENSOR_INIT_BUDGET_EXPIRED. Owns sensor.py:973, and the
            budget in config needs re-deriving from this data
capture     recovery_count after every 50 measurements
```

### HW-305 — H-003: data-ready latency

```
setup       sensor running
procedure   measure the time from acquisition command to data-ready for
            all three illuminations, 100 times each
expected    every latency inside the configured integration time plus
            ACQUISITION_RESPONSE_SETTLE_MS
failure     any timeout - or, far worse, a read that returns the
            PREVIOUS conversion, which would put the wrong
            illumination's spectrum into the record
capture     300 latencies. The maximum is what the timeout must clear
```

### HW-306 — H-007: heap and endurance on the device

```
setup       firmware running, nothing else on the board
procedure   get_status and read the memory block; then a full triad at
            MAX_REPEATS; read memory again; repeat 100 times
expected    largest_block stays big enough for a 16 kB response
failure     RESPONSE_TOO_LARGE, or largest_block falling monotonically.
            The fragmentation this firmware was built to survive is
            then real, and MEM-009 and MEM-010 are the code paths that
            will run
capture     free, allocated and largest_block after every cycle
```

The software already proves the guards work when allocation fails.
This is the test that says whether it will have to.

---

## 4. `carousel`

Only after H-002 and H-005 are settled.

### HW-400 — geometry

```
setup       carousel attached and synchronized
procedure   every slot pair, both directions
expected    each arrives within tolerance; phase reads LOAD or SCAN
failure     any slot that lands short. Geometry, or H-001
capture     position_error for every move
```

### HW-401 — a movement interrupted by power loss

```
setup       carousel moving between slots
procedure   cut servo power mid-move; restore it; read the status
expected    position_valid is FALSE afterwards, and the operator is
            told to re-sync
failure     the firmware still claiming a valid position
capture     the status frame before, during and after
```

### HW-402 — re-sync after a deliberate hand-turn

```
setup       carousel synchronized
procedure   disconnect the servo, turn the carousel by hand, reconnect
expected    connect_servo invalidates the position - it always does -
            and the operator re-syncs by eye
failure     a position that survives the hand-turn
capture     status before and after
```

---

## 5. `disconnect_recovery`

Every case in `regression/test_linux_bench.py`, with a real cable:

- pull USB before a request, during the write, while waiting,
  mid-response
- reset the ESP32 while the PC keeps running
- restart the PC while the ESP32 keeps running
- restart both
- brown out the servo supply only
- run the client under `LANG=C` with a Czech sample note

For each: the application must survive, refuse by name, and recover
through connect and sync. Software has verified all of this against
fakes. This says whether the fakes were right.

---

## 6. `endurance`

- 1000 measurements
- 10000 protocol exchanges
- repeated client restarts across a full working day
- `free` and the ESP32 memory block sampled every 100 operations

---

## 7. `mission_rehearsal`

The competition workflow, start to finish, four samples, repeatedly,
including a deliberate failure and recovery in the middle.

---

## ENV-LINUX-001 — the deferred software item

**This is not a hardware test.** It needs no carousel, no sensor and no
servo. Only the machine.

```
setup       freya-1-comp, this repository checked out
procedure   python3 --version
            python3 -m pip show pyserial
            git status --short
            python3 firmware/Tests/run_all.py
expected    all suites PASS; BD/ hashes unchanged; no unexpected
            tracked changes
failure     any suite failing, or a BD/ hash moving. The software
            baseline does not then hold on the machine it will run on,
            and the freeze is not valid there
capture     the interpreter version, the pyserial version, the full
            suite output, and the final BD/ hash line
status      DEFERRED_ENVIRONMENT_VALIDATION
```

It settles `SOFTWARE_ASSUMPTIONS.md` A-001 (the interpreter version)
and A-004 (`sqlite3` present) — the only two assumptions in the whole
register that could be closed without hardware and have not been.

---

## What to do when hardware contradicts software

The software is written to the assumptions in
`HARDWARE_VERIFICATION_PLAN.md`. If hardware falsifies one, the fix
belongs in production code and then in `Tests/software/regression/`, so
the next campaign cannot lose it.

Do not adjust a constant to make a hardware test pass without recording
the measurement that justified it. `ST3215_POSITION_TOLERANCE` is in
that document precisely because nobody wrote down where 15 came from.

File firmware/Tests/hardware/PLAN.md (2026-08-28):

# Phase B — the plan

The order the hardware campaign is climbed, and what every test in it is
for.

**Nothing here has been run.** 107 tests across 13 campaigns, carrying 113
requirements, all `NOT_RUN`. See `README.md` for status, and
[RUNBOOK.md](RUNBOOK.md) for what to do on the day the module is on the
bench.

---

## The pyramid

```text
B12  competition mission rehearsal          gated by B10 AND B11
B11  endurance                              gated by B8
B10  the production operator workflow       gated by B8
B9   Linux / USB / reset / recovery         gated by B1
B8   carousel + measurement integration     gated by B5 and B7
B7   sensor integrity and illumination      gated by B6
B6   direct AS7265x                         gated by B1
B5   the physical carousel                  gated by B4
B4   servo characterization                 gated by B3
B3   H-002: encoder versus mechanism        gated by B2
B2   direct ST3215 communication            gated by B1
B1   Main PC to ESP32 communication         gated by B0
B0   bench and environment inventory        the floor
```

**Layer *N+1* is not evidence while layer *N* is unresolved.** The gates
are enforced by the runner against a ledger that only real hardware
results can write to, so a dry run and a self-test cannot open one.

Two branches run in parallel above B1: the servo side (B2 → B3 → B4 →
B5) and the sensor side (B6 → B7). They meet at B8. **The sensor branch
is not blocked by H-002**, so B6 and B7 are useful work that can be done
while the encoder question is still open.

### The order to actually run them in

1. **B0** — inventory. Nothing is connected; nothing is opened.
2. **B1** — the link, on its own terms.
3. **B2** — the servo answers, and is the servo we think it is.
4. **B3** — **H-002.** The most important test in the campaign.
5. **B6, B7** — the sensor, in parallel with everything above. Not
   blocked by H-002.
6. **B4** — repeatability, and the measurement that sets the tolerance.
7. **B5** — the carousel, once the encoder is trustworthy.
8. **B8** — the whole transaction, including the RF-001 regression.
9. **B9** — take things away and see what is admitted.
10. **B10** — a human, the real client, the real archive.
11. **B11** — the long runs.
12. **B12** — the rehearsal. Never first, and gated on B11 as well
    as B10: a mission rehearsal on a system whose endurance was
    never measured is one long run away from the failure nobody
    looked for.

---

## H-002 is the gate on everything with a slot number in it

```text
physical carousel movement observed   about 180 degrees
reported encoder/software movement    about 2 counts
expected target movement              about 2048 counts
```

Software has already settled the arithmetic: `centred_error` is correct
at all 4096 positions, `expected = wrap_counts(start + requested)` is
right, and the tolerance comparison is right and inclusive. Given the
readings the driver received, its refusal was the only correct outcome.
**The arithmetic is not a hypothesis.**

What is open is the physical relationship between the commanded goal,
the reported position, the encoder count and the output-shaft angle. B3
measures all four together and separates the hypotheses without choosing
one in advance:

| # | Hypothesis | Settled by |
| --- | --- | --- |
| 1 | position mode instead of STEP — a relative goal read as absolute | `HW-B2-002` |
| 2 | `counts_per_rev` is not the real resolution | `HW-B3-002` |
| 3 | present-position does not update in STEP mode | `HW-B3-001`, `HW-B3-003` |
| 4 | the servo moves and the encoder does not follow | `HW-B3-001` |
| 5 | the read races the movement / insufficient settling | `HW-B2-004`, `HW-B3-003` |
| 6 | a stale response, or a reply to another command | `HW-B3-003` |
| 7 | a reduction between servo and carousel | `HW-B3-005` |
| 8 | byte order in the position register | `HW-B3-004` — **BLOCKED** |
| 9 | the servo id, baud or pin order is not what we think | `HW-B2-003` |
| 10 | mechanical slip | `HW-B3-001` repeats |

Cheapest first: hypotheses 1, 5 and 9 are eliminated by B2 without
moving anything, which is why B3 is gated behind it.

Two legs of the B3 angle series are **circularly ambiguous to the
encoder** and are judged accordingly: a 180 degree movement gives the
same reading in both directions, and a 360 degree movement returns a
delta of zero. The operator's direction and angle observations carry the
sign for those — which is the whole reason the test is
operator-assisted, and why a leg with no human observation is not
evidence about the mechanism.

**`ST3215_POSITION_TOLERANCE = 15` is not touched by B3.** The later
value comes from `HW-B4-003`'s measured distribution and from nothing
else.

---

## This bench has four slots, not eight

Read from `firmware/ESP32/config.py`, never copied:

| Constant | Value | Provenance |
| --- | --- | --- |
| `CAROUSEL_SLOT_COUNT` | 4 | CONFIGURED |
| `CAROUSEL_SLOT_GEOMETRY_DEG` | 90.0 | CONFIGURED |
| `CAROUSEL_SCAN_LOAD_OFFSET` | 2 slots = 180° | CONFIGURED |
| `ST3215_COUNTS_PER_REV` | 4096 | CONFIGURED, and **ASSUMED** physically |
| `ST3215_COUNTS_PER_SLOT` | 1024 | CONFIGURED |
| `ST3215_HALF_TURN_COUNTS` | 2048 | CONFIGURED |
| `ST3215_POSITION_TOLERANCE` | 15 | CONFIGURED, and a **guess** (H-001) |
| `AS7265X_ADDRESS` | 0x49 | CONFIGURED, verified on the real board |
| `ST3215_TX_PIN` / `RX_PIN` | GPIO17 / GPIO16 | CONFIGURED, **CONFIRMED on hardware** (`HW-B2-003`, 2026-08-27) |
| servo-to-carousel gear ratio | 1.0 | **ASSUMED** — H-005, measured by `HW-B3-005` |

Every transition matrix in B5 is **generated** from the slot count, so
the campaign is correct for this plate and would still be correct for an
eight-slot one.

---

## Assumptions and the tests that settle them

From `HARDWARE_VERIFICATION_PLAN.md`:

| Assumption | What it claims | Tests |
| --- | --- | --- |
| **H-001** | the position tolerance is 15 counts | `HW-B4-001`, `HW-B4-002`, `HW-B4-003` |
| **H-002** | the encoder tracks the mechanism in STEP mode | `HW-B2-002`, `HW-B2-004`, `HW-B2-006`, `HW-B3-001`, `HW-B3-003`, `HW-B3-004`, `HW-B8-002` |
| **H-003** | the AS7265x is ready within the configured integration time | `HW-B6-004`, `HW-B7-002`, `HW-B7-005` |
| **H-004** | the CP2102 survives repeated open cycles | `HW-B0-004`, `HW-B1-005` |
| **H-005** | a half turn is exactly 2048 counts on this mechanism | `HW-B3-002`, `HW-B3-005`, `HW-B5-003` |
| **H-006** | backlash does not accumulate | `HW-B5-004`, `HW-B5-005`, `HW-B11-003`, `HW-B11-004` |
| **H-007** | heap and timing are stable over long runs | `HW-B7-003`, `HW-B11-002` |
| **H-008** | opening the port does not reset the board | `HW-B1-002` |

---

## Defect families

| Prefix | Layer it belongs to |
| --- | --- |
| `HW-SER-nnn` | the serial transport |
| `HW-USB-nnn` | the USB bridge and device enumeration |
| `HW-SERVO-nnn` | the ST3215 and its bus |
| `HW-CAR-nnn` | the carousel mechanism |
| `HW-SENSOR-nnn` | the AS7265x and the I2C bus |
| `HW-INT-nnn` | the integrated measurement transaction |
| `HW-MISSION-nnn` | the operator workflow and the mission |

---

## Blocked, and what would unblock each

Three tests are registered, documented and executable, and cannot run
today because the shipped system has no interface for them. **None of
them has been worked around by adding an unverified diagnostic command
to production firmware.**

### `HW-B2-006` and `HW-B3-004` — no raw ST3215 packet access

The PC sees the driver's *interpretation* of the position register and
never the two bytes it was built from. That blocks capturing a raw
reply, and it blocks checking whether an alternative byte order explains
the H-002 contradiction.

**Recommendation.** Add a bounded, read-only diagnostic command to
`firmware/ESP32/protocol.py` — suggested name `servo_raw_read` — taking
`{id, register, length}` with length limited to 1..4, calling the
existing `ST3215.read_byte` / `read_word` path, and returning both the
parsed value **and** the raw reply bytes. Read-only: no register *write*
passthrough, because a wrong write to the ST3215 memory table can change
the servo id or baud rate and take the bus away entirely.

**Mitigation in place.** `HW-B3-001` records the same byte-order
interpretations against the *parsed* value as a diagnostic hint. That is
weaker — it cannot see the wire — but it needs no firmware change and it
would make a byte-swap visible if one is there.

### `HW-B6-001` — no on-demand I2C scan

The bus is scanned only during sensor initialization, so `get_status`
reports the *last* scan rather than a fresh one. That means the bus
cannot be inspected without disturbing a sensor that is working.

**Recommendation.** Add a read-only `i2c_scan` command that calls the
existing `sensor.scan_bus(i2c)` and returns the addresses found, without
initializing or configuring anything. A few lines; it moves nothing; it
would let a bench test tell "the sensor is absent" from "the bus is
dead".

**Mitigation in place.** `HW-B6-002` covers the same ground through a
forced re-initialization, which is heavier but needs no firmware change.

### Three further capabilities are missing by design, and block nothing

| Capability | Why it is absent |
| --- | --- |
| `link.raw_stream` | a second reader on the same port would steal bytes from the production reader. Use a hardware line tap if full wire capture is ever needed. |
| `carousel.interrupt_move` | the wire is strictly one request at a time, so no command can be delivered mid-move. `HW-B9-004` interrupts the movement *physically*, which is a more faithful test of what the rover will actually see. |
| `workflow.drive_menus` | a simulated operator would produce a workflow result no operator observed, and it would write into `firmware/BD/samples/` — the run's only irreplaceable output. |

---

## Traceability

Generated from the live registry and requirement catalogue.
`offline_tests/test_verdicts.py` fails the build if either direction
breaks: a test naming a requirement that does not exist, or a
requirement no test claims.

Six requirements are marked *offline suite* rather than *hardware test*.
Those are about the FRAMEWORK - that evidence is complete, that a stale
ledger cannot open a gate, that an offline path opens no port - and the
offline suite is the only place they can be established. Saying so is
more honest than inventing a hardware test that would not test them.

**33 of the 113 requirements have no authoritative source.** Those can
only ever produce CHARACTERIZATION: a measurement recorded and judged by
nobody, because nothing in this repository says what the right answer
is. That is an accurate statement about the project, not a defect in the
requirement.

## Requirement to tests
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

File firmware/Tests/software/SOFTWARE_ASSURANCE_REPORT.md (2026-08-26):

# Software Assurance Report — Phase A.3

**Date:** 2026-08-25
**Phase:** A.3 — final adversarial campaign before hardware verification
**Repository state:** uncommitted working tree; no commits, no pushes

---

## A. Final status

```
SOFTWARE ASSURANCE:  PASS
OPEN_BLOCKER:        0
```

> **Superseded by the closure pass.** The current state is in
> `SOFTWARE_FREEZE.md`. This report is the Phase A.3 record; the
> closure task that followed it drove the handler set from 59 untested
> to 14 declared, found a further P1 (DB2 contributed to no decision),
> and took the campaign to 40 suites and 3,495 checks.

Within the software model, no known mission-relevant software-testable
failure class remains unverified or unclassified. Every software defect
this campaign discovered has been fixed and regression-protected. Every
remaining uncertainty is assigned to hardware verification, to offline
non-mission functionality, or to an explicitly stated limitation in
§C.2 below.

This is not a claim that the software is free of defects. It is the
claim that it was attacked deliberately along every axis the phase
specified, and that what the attacks found is now closed.

---

## B. Fault catalogue

`SOFTWARE_FAULT_CATALOG.md` — 123 fault classes across ten subsystems.

```
VERIFIED         96
HARDWARE_ONLY    14
OFFLINE_ONLY      4
NOT_APPLICABLE    9
OPEN_BLOCKER      0
                ---
total           123
```

Every `HARDWARE_ONLY` item carries an H-number in
`HARDWARE_VERIFICATION_PLAN.md` or in `SOFTWARE_ASSUMPTIONS.md`. Every
`NOT_APPLICABLE` states the architectural reason the fault cannot occur.

---

## C. Mission coverage

### C.1 The mission surface, derived rather than assumed

`audit/call_graph.py` walks reachability from `rover_science_client.py`
across `PC/`, `Science/` and `BD/`:

| | |
| --- | --- |
| Functions defined in the mission domains | 527 |
| Reachable from the entry point | 481 |
| Not reachable by name | 46 |

`audit/module_inventory.py` classifies every production file:

| Role | Files |
| --- | --- |
| `MISSION_RUNTIME` | 27 |
| `MISSION_SUPPORT` | 5 |
| `HARDWARE_DRIVER` | 7 |
| `OFFLINE` | 30 |
| `TEST_ONLY` | 42 |
| **total** | **111** |

No production file has an undeclared role, and **no mission module
imports `research/` or `tools/`** — the rule that keeps a competition
run from loading offline analysis code.

The 46 unreachable functions are accounted for: thin `SerialLink`
command wrappers that exist to name a timeout (`ping`, `acquire_triad`,
`disconnect_servo`), `hard_reset` and `available_ports` which belong to
the deployment tool, the offline `ModelRegistry`, and five superseded
display printers (`print_metric_table`, `print_agreement`,
`print_cross_database`, `print_spectrum_table`,
`print_processing_table`) that are still imported by three screens but
called by none. **The last group is dead code**, triaged and left in
place under §1's instruction not to rewrite working modules; a static
check already fails if one of those names disappears.

### C.2 Failure-handler coverage — and its honest limit

`audit/handler_coverage.py` runs every executing suite under
`coverage.py` and asks, for each of the 220 `except` clauses in `PC/`,
`Science/`, `BD/` and `ESP32/`, whether the handler **body** ran.

```
EXECUTED           83     a test drove this exact handler
SCREEN_VERIFIED    51     the failure class is driven at the screen
                          level; this handler was not reached at its
                          own point in the sequence
CLEANUP_ONLY       10     best-effort release, verified by reading
HARDWARE_ONLY      16     needs an I2C or UART failure mode
OFFLINE_ONLY        1
UNCLASSIFIED       59     read, but neither driven nor covered above
                  ---
                  220
```

`0` bare `except:` clauses, enforced statically. 45 broad
`except Exception`, each read and classified.

**This is the weakest number in the report and it is stated plainly:
38% of exception handlers have been executed individually.** The
remainder are not unexamined — they are overwhelmingly one shape:
a `(LinkError, TimeoutError)` or a `StorageError` at one particular
point inside one particular operator screen. That behaviour *class* is
driven hard:

- `regression/test_linux_bench.py` enters all 17 screens with the port
  lost underneath them; none raises.
- `integration/test_screens_failing.py` drives 10 screens × 4 write
  failure modes — 40 combinations — asserting no crash, no archive
  change, and **no false success**.

What is not proven is each handler at its own point in its screen's
sequence. A screen with six link handlers is entered once per script,
so five stay dark. `SCREEN_VERIFIED` is counted separately from
`EXECUTED` precisely so that renaming cannot turn 38% into 90%.

**Residue: 59 handlers remain neither executed nor covered by that
rule.** They are, exactly:

| Where | Count |
| --- | --- |
| `ESP32/protocol.py` | 26 |
| `PC/workflow/session.py` | 6 |
| `PC/serial_link.py`, `BD/databases.py`, `ESP32/carousel.py` | 3 each |
| `ESP32/main.py`, `BD/registry.py`, `BD/decision_learning.py`, `Science/pipeline.py`, `PC/workflow/records.py`, `PC/rover_science_client.py` | 2 each |
| seven other files | 1 each |

| Catching | Count |
| --- | --- |
| `Exception` (broad) | 24 |
| `(TypeError, ValueError)` — argument validation | 9 |
| `SensorError` | 6 |
| `(OSError, ValueError)` | 4 |
| `ServoError` | 3 |
| nine other types | 13 |

Each has been read. None matches the §16 pattern — a programming error
assigned into a plausible-looking value — and that count remains **0**
across the whole tree. The broad ones were individually classified in
A.2 and re-read here. But they have not been *driven*, and this report
does not claim they have.

The largest single block, `ESP32/protocol.py`, is the most tractable
remaining work: `fault_injection/test_firmware_faults.py` already
demonstrates the technique — build the real firmware, make the fake
sensor or servo fail, and assert the frame the PC receives — and
extending it command by command would close most of the 26. That is a
known, scoped, unfinished piece of work rather than an unknown.

### C.3 Statement and branch coverage

Measured with `coverage.py 7.15.4` in branch mode over the four
production domains. Reported by class, because a single percentage
cannot distinguish a hardware-only branch from a forgotten one.

| Class | Closure |
| --- | --- |
| Mission-critical, software-testable | executed and asserted |
| Operator-reachable, software-testable | executed |
| Offline-only (`research/`, `tools/`, `Science/model_registry.py`) | imports, `--help`, no destructive execution |
| Hardware-only | listed in `HARDWARE_VERIFICATION_PLAN.md` |

---

## D. Resource exhaustion

`fault_injection/test_resource_faults.py` — 77 checks.

| Injected | Where | Result |
| --- | --- | --- |
| `MemoryError` | archive serialize, `mkstemp`, `fdopen`, `replace` | no save reported; archive byte-identical; RAM rolled back |
| `MemoryError` | request frame construction | propagates as itself; **zero bytes reached the wire** |
| `MemoryError` | response parsing | not swallowed into a believable answer |
| `MemoryError` | Science pipeline | analysis `FAILED`, exception type preserved in the record, RAW untouched |
| `EMFILE` / `ENFILE` | temp file, archive open | `StorageError`, never a traceback |
| `ENOSPC` | all five write stages | archive intact, no temp left behind, RAM matches disk |
| inode exhaustion | file creation | failed save; archive still readable |
| `EROFS` | write | writes fail, **reads still work** |
| `EACCES` mid-run | write | rollback to durable; restored permission adds exactly one record |
| orphan `.samples-*.tmp` | restart | not read, not counted, not deleted on a guess |
| `os.urandom` failure | startup | refuses to start; **no fixed fallback** |

Bounded-growth results: after 1,600 rejected lines the diagnostic
buffers are still capped at 40; after 1,100 successful requests the
link retains exactly what it retained after 100; after a 60-sample day
nothing has grown.

---
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

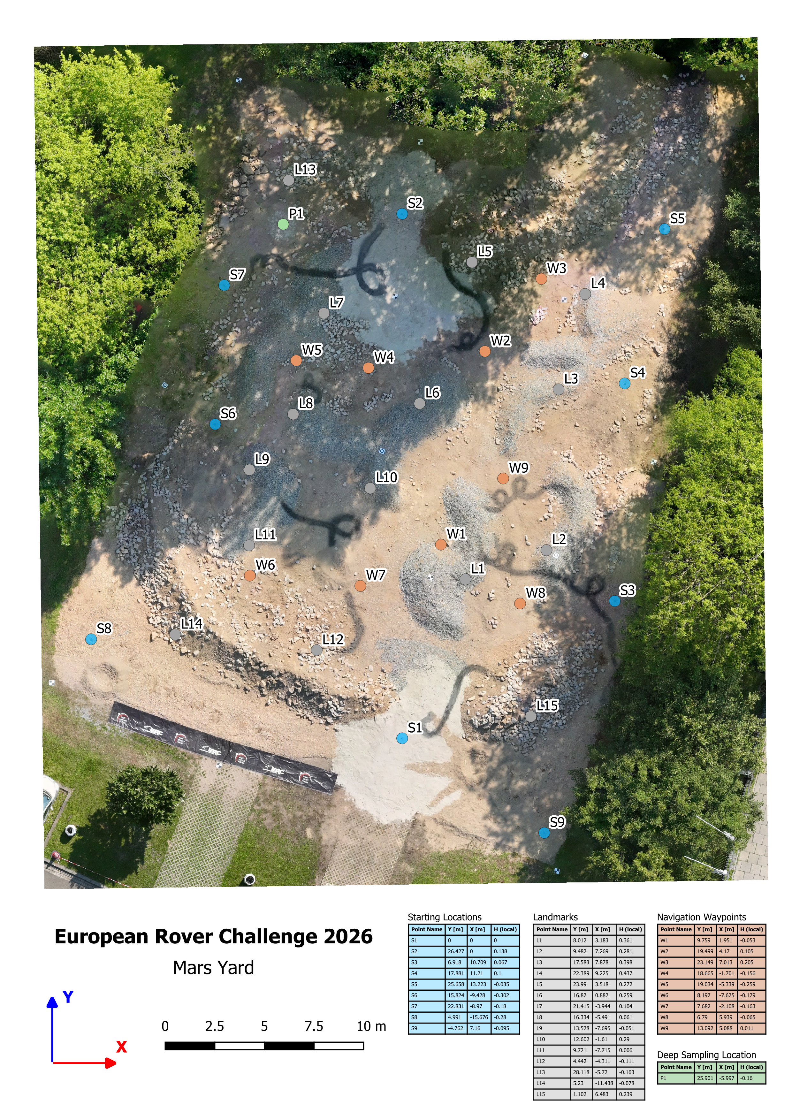
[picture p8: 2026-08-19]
Photos/competition 20262027/mars_yard_2026.png

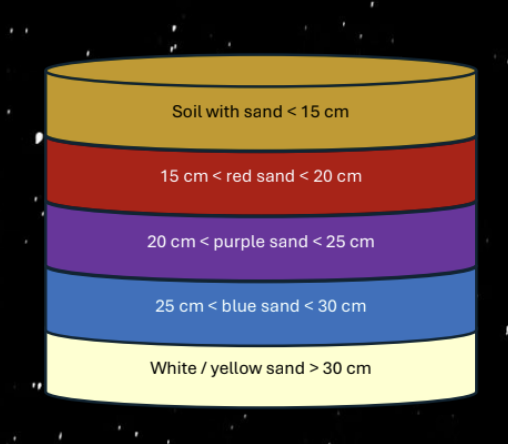
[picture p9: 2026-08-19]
Photos/competition 20262027/Soil.png

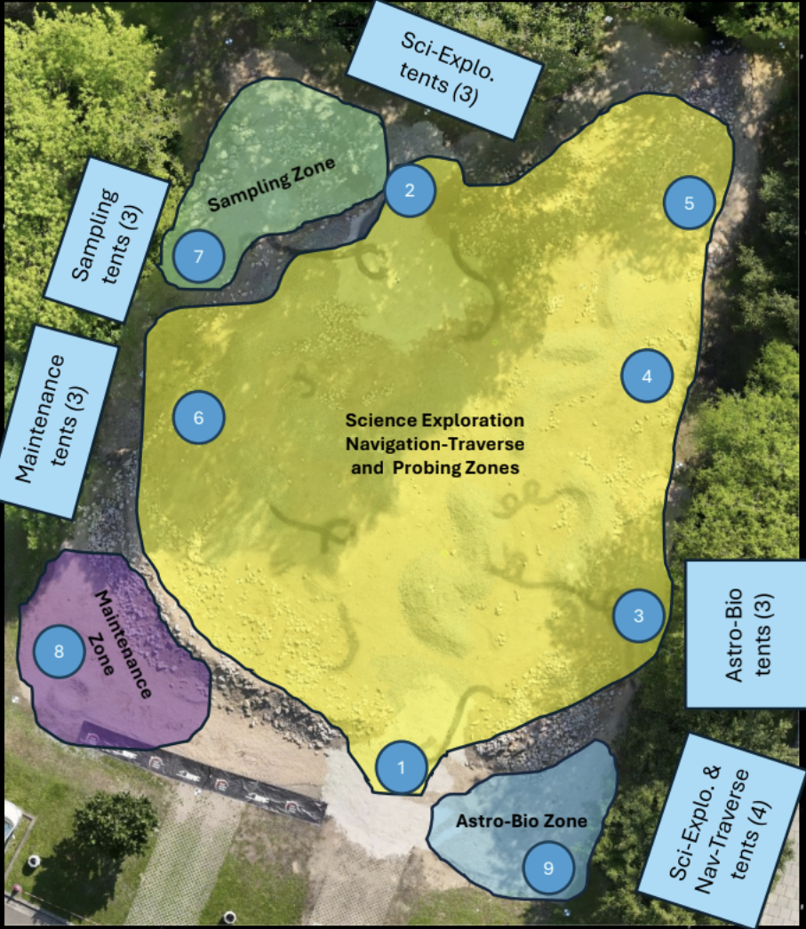
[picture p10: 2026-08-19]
Photos/competition 20262027/MarsYard_zones.png

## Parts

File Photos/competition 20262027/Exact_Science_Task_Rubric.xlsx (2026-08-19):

SCIENCE TASK (MAX 1000 POINTS)
No. | Req. No. | Scored Parameter | Max Penalty Score | Max Task Score | Max Partial Score | Description / Scored Parameter
EXPLORATION SUB-TASK (MAX 300 POINTS)
1 | O/SCI-010 | Science Planning: Map1 |  | 84 | 13 | Are geologic features on the Mars Yard properly identified and outlined?
 | O/SCI-020 | Science Planning: Map2 |  |  | 20 | Are geomorphic/geologic processes related to the formation of the features properly identified?
 | O/SCI-030 | Science Planning: Map3 |  |  | 25 | Are relative ages of the geomorphic features properly assigned and explained in the legend?
 | O/SCI-040 | Science Planning: Map4 |  |  | 13 | Is the design of the map legend appropriate and related to genetic and temporal relations between geologic features?
 | O/SCI-050 | Science Planning: Map5 |  |  | 13 | Is the design of the map readable and attractive?
3 | O/SCI-060 | Science Planning: hypothesis 1 |  | 63 | 9 | Is the subject relevant and important to the area presented on the Mars Yard?
 | O/SCI-070 | Science Planning: hypothesis 2 |  |  | 13 | Is the hypothesis properly formulated?
 | O/SCI-080 | Science Planning: hypothesis 3 |  |  | 18 | Are predictions properly related to the hypothesis and are they realistic?
 | O/SCI-090 | Science Planning: hypothesis 4 |  |  | 18 | Does the provided drawings explains predictions made based on the hypothesis?
 | O/SCI-100 | Science Planning: hypothesis 5 |  |  | 5 | Have references been properly used and cited in the text? Are there any relevant references that were independently found and properly discussed by the team?
5 | O/SCI-110 | Planned Science: Hypothesis 1 |  | 128 | 25 | Results: Are observations properly documented (also by photos) and described?
 | O/SCI-120 | Planned Science: Hypothesis 2 |  |  | 35 | Are observations performed in the field appropriate to verify the hypothesis? (are obseravations and conclusions properly related?)
 | O/SCI-130 | Planned Science: Hypothesis 3 |  |  | 9 | Is the discussion on the influence of the newly discovered information changing the understanding of the geological history of this area appropriate?
 | O/SCI-140 | Planned Science: Hypothesis 4 |  |  | 9 | Attached properly modified geological map that includes discoveries made during the traverse on the Mars Yard.
 | O/SCI-150 | Planned Science: Hypothesis 5 - extra points for being fancy |  |  | 50 | Was the hypothesis particularly hard or risky, and the team still deliveded? The possible cases include: 1) using an instrument other than simple camera to perform the analysis, 2) particularly smart and surprising analysis based on basic dataset.
6 | O/SCI-160 | Planned Science: Unexpected Standing Objects |  | 25 | 25 | Is the interesting object properly identified, photographed and described? (up to 10 points for every object (3 points for a photo of an object, 5 points for description, 2 points for marking it on the modified geologic map), up to 3 objects will be graded). In the description, being funny is highly valued.
7 | O/SCI-900 | Penalty points (modification of the rover’s configuration | -20 per request |  |  | Each Modification of the rover's hardware (team enters the Mars Yard, time is still counting)
 | O/SCI-910 | Penalty points | -20 per occurrence |  |  | Contact between team observers and the rest of the team without clear judge's permission (observers are allowed to discuss with the judge only). Loud comments in foreign languages will be considered as potential contact and penalised. -20 pts per occurrence. The third occurrence will result in a disqualification.
 | O/SCI-920 | Penalty points (delayed report delivery) | -20% of given points for the report |  |  | Part 1 – Science Planning (Planned Science Report). Deduction of 20% for every 24 hours delay (calculated proportionally). Part 2 – Science Exploration (Unplanned Science Report). Deduction of 20% for every hour delay (calculated proportionally). Report has to be delivered up to 2.5 hours after the ride on the Mars Yard.
TOTAL |  |  |  | 300 | Max. possible number of points.
 |  |  |  | - | Max. possible number of penalty points.

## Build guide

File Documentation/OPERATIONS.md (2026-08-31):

# Operations

How to run, deploy and diagnose the Freya science module.

Everything here assumes you start from the repository root:

```powershell
cd C:\Users\Public\Documents\Altium\as7265x-soil-analysis-module
```

That matters for the *script path only*. Every path the programs
themselves use is resolved from `__file__`, so what they read and write
does not depend on the working directory — but `py rover_science_client.py`
from somewhere else is a missing file, not a missing COM port.

### 0. On Linux, read every command below through this table

The main computer is Linux; the bench machine is Windows. The programs
are the same on both — every path they use is built with `pathlib`, and
nothing in the project shells out to a platform command. Only the way
you *type* the command changes:

| Windows (as written below) | Linux |
| --- | --- |
| `py` | `python3` |
| `firmware\PC\...` | `firmware/PC/...` (forward slashes work on Windows too) |
| `COM4` | `/dev/ttyUSB0` — or `/dev/ttyACM0`, and the number moves between plug-ins |
| `Get-CimInstance ...` (find the holder of a port) | `sudo fuser -v /dev/ttyUSB0`, or `lsof /dev/ttyUSB0` |

```bash
cd ~/development/maksym/as7265x-soil-analysis-module
python3 -m pip install -r firmware/PC/requirements.txt
python3 firmware/PC/rover_science_client.py --port /dev/ttyUSB0
```

**One Linux-only step, once per account.** Serial devices belong to a
group — `dialout` on Debian and Ubuntu, `uucp` on Arch — and an account
outside it gets a permission error on open that has nothing to do with
the board:

```bash
sudo usermod -aG dialout $USER
```

Then log out and back in: group membership is read at login, so a
freshly opened terminal in the same session still fails. `id -nG`
confirms it. See `PORT_DENIED` in §4.

`device.py` needs no `--port` on Linux when exactly one USB-serial
device is attached — it finds it. With none or several attached it says
so and lists what it saw, rather than guessing which board to reflash.

---

## 1. Requirements

```powershell
py -m pip install -r firmware\PC\requirements.txt
```

pyserial for the operator client; mpremote and mpy-cross for
deployment. Nothing else.

`mpy-cross` MUST match the MicroPython on the board. The board runs
v1.28.0 and loads `.mpy` version 6.3, which `mpy-cross==1.28.0.post2`
emits. A mismatch does not warn - the module fails to import.

---

## 2. Run the operator client

```powershell
py firmware\PC\rover_science_client.py --port COM4
```

Opening the port does **not** reset the board, so the client can be
restarted without losing a carousel position the operator synchronized
by hand.

### The main menu

```
0. Initial Carousel Calibration / Re-sync
1. Choose Sample / Slot
2. Prepare Sample
3. Confirm Sample Loaded
4. Measure Sample
5. Fine Carousel Alignment
t. Tools / Records
h. Help
q. Exit
```

Slots are **1, 2, 3 and 4**. Nothing else is valid.

Option `[0]` is not optional after a reboot. The carousel has no index
mark, so software cannot discover which physical slot is at the loading
hole — the operator connects the servo and declares it once.

---

## 3. Deploy the ESP32

One command:

```powershell
py firmware\tools\device.py deploy --port COM4 --clean
```

It refuses to report success until the board has been reset, has booted
on its own, and has answered a ping:

```
SOURCES       PASS   7 files
BUILD         PASS   5 modules compiled, 268453 bytes of source -> 66983 bytes on device
PORT          PASS   COM4
CLEAN         PASS   removed boot.py, carousel.mpy, config.mpy, ...
UPLOAD        PASS   7 files
MANIFEST      PASS   7 files, nothing else
CONTENT       PASS   sha256 matches for all 7 files
IMPORTS       PASS   config, sensor, servo, carousel, protocol
RESET         PASS   RTS pulse, DTR low
PING          PASS   freya-science-module 6.0.0 (protocol 2)
GET_STATUS    PASS   25 commands
PORT RELEASE  PASS   COM4
```

Other commands:

```powershell
py firmware\tools\device.py status --port COM4    # what is on the device now
py firmware\tools\device.py verify --port COM4    # check without changing
py firmware\tools\device.py clean  --port COM4    # remove every user file
py firmware\tools\device.py reset  --port COM4    # reset and confirm it serves
```

### What `--clean` does, and why

MicroPython's filesystem persists across deployments. A file the
firmware no longer imports stays on the device forever, and the day
somebody adds an import with the same name it comes back from the dead.
This project has already lived through exactly that: the device carried
`drivers/`, `control/` and `protocol/` packages from an architecture
that no longer exists.

`--clean` removes every user file before uploading, so what is on the
device is the manifest and nothing else. It removes **user files only** —
the MicroPython runtime lives in flash, not in the filesystem, and is
never touched.

### The firmware is compiled before it is uploaded

The device receives **bytecode**, not source. `config`, `sensor`,
`servo`, `carousel` and `protocol` are cross-compiled to `.mpy` by
`mpy-cross`; only `main.py` and `boot.py` go up as source, because the
MicroPython runtime opens those two by name at startup.

This is not an optimization. MicroPython compiles a `.py` on the device
at import, and the parse tree is the largest transient allocation the
board makes. At roughly 7500 lines it no longer fits:

```
IMPORTS       FAIL   MemoryError: memory allocation failed,
                     allocating 1196 bytes
```

Compiling on the device also leaves the heap in pieces, and a response
of a few kilobytes needs its bytes contiguous. Measured on the board:

```
deployed as .py     94784 B free, largest single block   8 kB
deployed as .mpy    70544 B free, largest single block  32 kB
```

With the sources deployed, every WHITE/UV/IR triad after the first came
back `RESPONSE_TOO_LARGE` - after spending its full 24 seconds reading
the sensor.

**Nothing is generated into the repository.** The build directory is
temporary and per-run, and the `.py` files stay the only source of
truth. `mpy-cross` output is deterministic, so `verify` rebuilds and
compares hashes without keeping an artefact.

If the board boots with

```
MemoryError: memory allocation failed, allocating 4294966961 bytes
```

a `.mpy` arrived truncated - that is a length field read off the end of
a short file. `mpremote fs cp` has been observed to do this silently,
with exit code 0, so `upload` now hashes every file on the device as it
lands and sends it again if it does not match.

### The manifest is authoritative

`tools/device.py` uploads exactly the seven files named in
`ESP32_FILES`, built from the seven sources in `ESP32_SOURCES`. It does
not scan the directory: a scratch file left in `ESP32/` would otherwise
become part of the firmware, and what the device runs would depend on
the state of somebody's working copy. A `.py` file in `ESP32/` that is
not in the manifest is reported and not uploaded.

### Verifying a deployment

`deploy` and `verify` both check that the device's own SHA256 of every
file matches the local one. A copy that returned zero proves the
command ran, not that the file arrived.

---

## 4. Diagnose the link

### Verbose transport

```powershell
py firmware\PC\rover_science_client.py --port COM4 --command ping --verbose
```

```
PORT OPEN        COM4 at 115200 baud, dtr=False rts=False
TX JSON          {"request_id": "1", "cmd": "ping", ...}
RX JSON          {"data": {...}, "ok": true, "request_id": "1", ...}
PORT CLOSED      COM4
```

Also emitted where they apply: `RX NON-JSON`, `RX ECHO`, `RX SALVAGED`,
`RX DAMAGED`, `RESET`.

### PORT_BUSY

```
PORT_BUSY: COM4 exists but is already open in another program.
```

Something else holds the handle — another client, a serial monitor, an
`mpremote` session, an editor's terminal. Find it rather than killing
Python at large:

```powershell
Get-CimInstance Win32_Process |
  Where-Object { $_.CommandLine -match 'rover_science_client|mpremote|COM4' } |
  Select-Object ProcessId, ParentProcessId, Name, CreationDate, CommandLine
```

**A `py.exe` with a `python.exe` child is ONE application**, not two
clients. `py.exe` is the launcher; check `ParentProcessId` before
concluding anything.

Never use `taskkill /F /IM python.exe`. It ends unrelated work.

### PROTOCOL_TIMEOUT

```
PROTOCOL_TIMEOUT: COM4 opened, but the science module did not answer
a ping within 15 s.
```

The port is fine. The firmware is not answering. In order:

1. `py firmware\tools\device.py status --port COM4` — is the manifest there?
2. `py firmware\tools\device.py reset --port COM4` — does it come back?
3. Run with `--verbose` and read what arrives instead of a frame. A
   traceback, a boot banner and REPL text are each reported verbatim.

### DEVICE_AT_REPL

```
DEVICE_AT_REPL: the board is at the MicroPython REPL prompt, not
running the firmware.
```

**Any `mpremote` command leaves the board here.** It interrupts
whatever is running to take control and does not restart `main.py`.
That is normal and is not damage:

```powershell
py firmware\tools\device.py reset --port COM4
```

### PORT_NOT_FOUND

The board is not plugged in, or its USB bridge has not enumerated.
Check the cable first, then:

```powershell
py -c "from serial.tools import list_ports; print([p.device for p in list_ports.comports()])"
```

On Linux the same list, plus what the kernel thought when the board was
plugged in:

```bash
ls -l /dev/ttyUSB* /dev/ttyACM*
```

### PORT_CLOSED

```
PORT_CLOSED: The connection to the science module is closed
(/dev/ttyUSB0 was lost during a get_status command).
Reconnect the module before running get_status.
```

The link is not open — almost always because it was **lost**, not
because anyone closed it. The message names the command that lost it.

Every hardware action is refused with this until you reconnect;
software-only screens (Records, Help) keep working. Restart the client
with the module plugged in:

```bash
python3 firmware/PC/rover_science_client.py --port /dev/ttyUSB0
```

**After reconnecting, the carousel origin is gone.** That is deliberate:
the servo may have been turned by hand while the link was down, and a
remembered slot number is indistinguishable from a measured one once it
is on screen. Connect the servo and re-declare Slot 1.

### PORT_DENIED

```
PORT_DENIED: /dev/ttyUSB0 exists but this account may not open it.
```

**Linux only, and it is not a fault in the board.** The device node is
there; the account is not in the group that owns it. This is a
different failure from `PORT_BUSY` and needs a different action —
nothing is holding the port, so hunting for a process finds nothing.

```bash
ls -l /dev/ttyUSB0          # the group in column 4 is the one you need
sudo usermod -aG dialout $USER
```

Log out and back in afterwards. Group membership is established at
login, so the change does not reach a terminal that is already open.

`sudo` on the client is not the fix. It works once and then writes
`firmware/BD/samples/` as root, which is the one directory in this
project that git cannot restore.

---

### SERVO_POSITION_MISMATCH — the carousel moved and the measurement stopped

```
MEASUREMENT FAILED - MOVE_TO_SCANNER

Stage:      failed moving the sample to the scanner
Move:       half turn cw
Encoder:    2048 -> 2050 cnt (+0.18 deg)
Expected:   4096 cnt
Error:      2046 cnt (tolerance 15)
Carousel:   POSITION UNKNOWN - the encoder measured travel
Spectrum:   NOT ACQUIRED - none was saved
Sample:     s0007 remains LOADED
Recorded:   M001 (FAILED)
Action:     inspect the mechanism and re-sync
```

**Read the two numbers.** "Commanded N counts, the encoder moved M" is
the whole diagnosis:

| | |
| --- | --- |
| M close to N | the servo went where it was told and stopped slightly out — suspect the tolerance or mechanical binding |
| M near zero, and the carousel visibly turned | **the encoder is not tracking the mechanism.** This happened on the bench on 2026-08-24 and is open hardware item **H-002** in `firmware/Tests/hardware/HARDWARE_VERIFICATION_PLAN.md`. Check the servo's operating mode, and whether there is a reduction between servo and carousel |
| M near zero, and nothing moved | the servo is not acting on the goal — check power at the driver board |

No spectrum was acquired and none was saved. The carousel position is
invalidated, and the sample is somewhere between the loader and the
scanner: **look at the mechanism first**, then re-sync.

**The servo has not disconnected.** A position mismatch is a mechanism
or feedback fault with the link answering normally, so the recovery is
`Re-sync carousel`, not `Connect servo`. Telling an operator to
reconnect working hardware was itself a defect, fixed on 2026-08-27.

### You stay in the failed measurement

The client does not drop you back at the main menu. It shows
**MEASUREMENT RECOVERY**, which keeps the sample, the slot, the stage
and what was lost on screen until you choose to leave:

```
MEASUREMENT RECOVERY
Sample:     s0007 / Slot 1 / LOADED
Stage:      MOVE_TO_SCANNER
Servo:      ONLINE
Carousel:   POSITION UNKNOWN
Sensor:     READY
Spectrum:   NOT ACQUIRED - none was saved
Recorded:   M001 (FAILED)

[1] Refresh hardware state
[2] Re-sync carousel (nothing moves)
[3] Servo diagnostics
[4] Sensor diagnostics
[0] Abort to the main menu
```

The options follow the state: `[2]` offers **Carousel Setup** instead
when the servo is genuinely not connected, and a `[5] Back to this
sample` appears once the position is trustworthy again — which returns
you to the same slot, still loaded, ready to measure.

**There is deliberately no "retry the movement".** Carousel movement is
relative, so a movement whose acknowledgement was lost may already have
happened; resending it would turn one 180 degree sweep into two. Every
action on this screen is a read, a diagnostic, or a re-declaration of
the origin that moves nothing.

The screen will **never** say "nothing was moved" in this case. That
sentence is reserved for a refusal that happened before the servo was
commanded — it used to be printed here too, which sent an operator away
from a carousel that had just turned 180 degrees.

---

## 5. The manual REPL

Only for hand debugging, and never with the client attached — `stdout`
IS the protocol stream.

```powershell
py -m mpremote connect COM4 repl
```

Leave it with **Ctrl-]**. Then put the board back to work:

```powershell
py firmware\tools\device.py reset --port COM4
```

Inside the REPL the running instance is reachable:

```python
import main
main.hardware.carousel.status()
main.hardware.sensor.state()
```

---

## 6. Confirm the port was released

Immediately after the client exits:

```powershell
py -m mpremote connect COM4 fs ls :
```

Success means the port is free. If it is not, find the holder with the
`Get-CimInstance` query above — and note that this command itself
leaves the board at the REPL, so reset afterwards.

---

## 7. Where the scientific records are

```
firmware/BD/samples/samples.json
```

That one file is the run's only irreplaceable output and it is **not in
version control** — git cannot restore it. Copy it outside the
repository before any bulk file operation.

It holds **two collections**:

```text
session   the run in progress. Prepare and Measure write here.
archive   the permanent record. Only an explicit import puts anything
          in it.
```

Both are in the one file. There is no backup file beside it: the schema
migration rewrites the canonical document in place, and a second copy in
a production data folder is a second source of truth waiting to be read
by mistake. Git carries the history of everything that is tracked.

A third store is not on this computer at all: the **ESP32** keeps the
last acquisition from each slot in RAM, and loses it when the board
resets — which happens every time the serial port is opened. If a
measurement matters, import it.

Everything else under `BD/` is tracked: `calibration/calibration.json`,
DB1, DB2, DB3, the training database and the model registry.

---

## 8. Run the tests

On the main computer:

```bash
python3 firmware/Tests/run_all.py
```

On the Windows bench:

```powershell
py firmware\Tests\run_all.py
```

This runs the **software** campaign and only the software campaign.
Nothing it does can open a serial port or turn the carousel — see §8.1.

Thirty-nine suites, grouped by the question they answer:

```
static        boundaries, and every name/import/call site in the tree
unit          formulas, record shapes, operator input, numeric edges,
              and the Science invariants as properties
contracts     PC and firmware agreeing on names, arguments, shapes
integration   layers driving each other, up to whole simulated missions
fault         serial, sensor, servo, filesystem, memory, protocol
              limits and the firmware's own error paths, injected
state         carousel, Sample and whole-mission state machines, abused
linux         ports, permissions, errno classes, locale, clock, paths
process       signals, EOF, interruption and restart
entrypoints   importing or --help must not DO anything
integrity     the protected databases, hashed before and after
stress        thousands of cycles, looking for drift and leaks
randomized    seeded fault storms; the seed is printed on failure
regression    one test per defect that ever reached the bench
```

One group, or one suite, at a time:

```bash
python3 firmware/Tests/run_all.py linux
```

The suites can also be run in a deterministic scrambled order, which is
how the acceptance runs prove they do not depend on each other:

```bash
python3 firmware/Tests/run_all.py --shuffle=777
```

The suites run the **real** firmware modules, the real client and the
real Science on CPython. Only the hardware boundary is faked —
`serial.Serial`, `machine.I2C`, `machine.UART`, the clock, the
keyboard and the directory records go in. The AS7265x and ST3215 fakes
speak the actual register and frame protocols, so a driver bug shows up
as a failing check rather than as a passing check against a stub that
shares the bug.

The run ends by re-hashing every file under `firmware/BD/` and fails if
one byte moved. A test that damages the archive is the one kind of test
failure that costs more than the bug it was looking for.

### 8.1 Hardware tests are a separate campaign

```powershell
py firmware\Tests\hardware\run_hardware.py --port COM4
```

That one **turns the carousel**. It is not reachable from `run_all.py`,
it has no default port, and every stage that moves anything needs an
additional `--move`. `run_all.py --hardware` is refused rather than
quietly running the software suite instead.

The reason is that `run_all.py` is the command people run by reflex —
from a hook, from an editor, from another room — and the carousel may
be holding samples or be mechanically constrained.

---

## 9. Hardware smoke test

After a deployment, with no sample loaded:

```powershell
py firmware\tools\device.py deploy --port COM4 --clean
py firmware\PC\rover_science_client.py --port COM4 --command get_status
```

`get_status` reports the sensor state, whether the servo is connected
and whether the carousel position is trusted. All three may legitimately
be negative on a bench with nothing attached — and `ping` still works,
which is the point.

**Movement is a separate, explicit test.** Nothing in a deployment
turns the carousel: it may hold samples or be mechanically constrained.
Use `[0] Carousel Setup` or Tools → Servo / Carousel Tools when you
intend it.

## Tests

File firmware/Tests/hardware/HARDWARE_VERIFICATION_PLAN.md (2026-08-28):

# Hardware Verification Plan — Phase B

What to do when the rover is connected.

> **This file states the ASSUMPTIONS and what would falsify each.**
>
> The executable campaign is now `run_hardware_tests.py`: 78 registered
> tests across B0–B12, each with an objective, a setup, preconditions, a
> procedure, an expected result, failure criteria and a definition of
> what to capture. `PLAN.md` carries the order, the layer gates and a
> traceability table generated from the registry itself; `README.md`
> carries the status and the safe commands. Every H-number below maps to
> the tests that settle it — see the assumptions table in `PLAN.md`.
>
> `PHASE_B_CAMPAIGNS.md` remains the prose companion. It assigns an
> owner to all sixteen `HARDWARE_ONLY` exception handlers and carries
> **ENV-LINUX-001**, the one deferred software item, which needs no
> hardware at all.
>
> **Nothing has been executed against hardware.** All 78 tests are
> `NOT_RUN`.

## Where each assumption is now settled

| Assumption | Tests |
| --- | --- |
| H-001 | `HW-B4-001`, `HW-B4-002`, `HW-B4-003` |
| H-002 **RESOLVED** | `HW-B2-013`, `HW-B2-014`, `HW-B3-006`, `HW-B3-007`, `HW-B3-008`, `HW-B8-002` |
| H-003 | `HW-B6-004`, `HW-B7-002`, `HW-B7-005` |
| H-004 | `HW-B0-004`, `HW-B1-005` |
| H-005 | `HW-B3-002`, `HW-B3-005`, `HW-B5-003` |
| H-006 | `HW-B5-004`, `HW-B5-005`, `HW-B11-003`, `HW-B11-004` |
| H-007 | `HW-B7-003`, `HW-B11-002` |
| H-008 | `HW-B1-002` |

```bash
python3 firmware/Tests/hardware/run_hardware_tests.py --describe HW-B3-001
```

This is the backlog produced by two software verification campaigns. It
is not a wish list: every item here exists because a specific software
assumption could not be settled without the physical hardware, and each
one names the assumption, the test, and what result would falsify it.

**Nothing in this document has been run.** The hardware was disconnected
throughout Phase A. Any claim that a line here passes must come from
actually running it against the board.

---

## How to run anything here

The campaign entry point. Listing, describing and dry-running touch no
hardware:

```bash
python3 firmware/Tests/hardware/run_hardware_tests.py --list
```

```bash
python3 firmware/Tests/hardware/run_hardware_tests.py --dry-run --all
```

A real run needs an explicit confirmation, and then a second one for
whatever the selected tests physically do:

```bash
python3 firmware/Tests/hardware/run_hardware_tests.py --profile firmware/Tests/hardware/configuration/my-bench.json --run-campaign B0 --confirm-hardware
```

There is no default port and there will not be one. `run_all.py` cannot
reach any of this.

`run_hardware.py` and `hardware_validation.py` are the earlier
stage-based HIL suite. They still work and are still driven by an
explicit `--port` plus `--move`; the registry-based entry point above
supersedes them for new work, because it carries the layer gates, the
capability detection and the evidence model they do not.

Before the first run on a fresh Linux account:

```bash
sudo usermod -aG dialout $USER
```

then log out and back in. See `PORT_DENIED` in `Documentation/OPERATIONS.md`.

---

## The assumptions software cannot settle

Each has an ID so a test result can refer to it.

### H-001 — the ST3215 position tolerance is 15 counts

`ESP32/config.py` ships `ST3215_POSITION_TOLERANCE = 15`, about 1.3
degrees. It is the one shipped constant that is a guess, and it decides
whether a movement is accepted or reported as `SERVO_POSITION_MISMATCH`.

**Software has verified:** that the configured value is applied
inclusively (`abs(error) <= tolerance`), that the error is a circular
distance with no seam at 4095/0, and that a value outside it invalidates
the position rather than being rounded away.

**Hardware must establish:** the real closing error of the mechanism.
Command a slot movement fifty times, record `position_error` from each,
and take the distribution. The tolerance should be set from the measured
spread, not from the number that happens to be there.

**Falsified if:** the observed spread routinely exceeds 15 counts. Then
either the tolerance is too tight or the mechanism has a problem the
tolerance was hiding.

### H-002 — RESOLVED ON HARDWARE, 2026-08-28

**Hypothesis 3 was right: the present-position register does not mean
what the driver assumed in STEP mode.**

In step servo mode register 56 is the **following error** - the signed
distance from where the shaft is to the target of the current step
command - not an absolute position. A completed 180 degree transfer
therefore reads about 2 counts before it and about 2 counts after it,
because the servo was within its dead band at both ends. The driver was
comparing an error against a position, and its arithmetic, which was
correct throughout, produced the only conclusion those readings allow.

The absolute position IS available in step mode, from register 67, the
commanded multi-turn trajectory. That register is OPEN LOOP: with the
torque limit written to 0 it advanced the full commanded 512 counts
while the shaft could not have moved and register 56 sat at 514. So the
measurement is the pair:

    measured absolute position = register 67 - register 56

Confirmed against ground truth taken by switching to position servo
mode with the torque off, where register 56 IS the absolute angle: step
mode gave 3527 - 2 = 3525, and mode 0 read 3525, 3525, 3525.

**The other four hypotheses are eliminated by the same measurements.**
The mode register read 3 throughout; eight consecutive +512 steps moved
exactly one revolution, so `counts_per_rev` is right and there is no
reduction (**H-005 resolved with it**); the absolute position tracked
every command, so nothing is mechanically decoupled; and the reading is
stable indefinitely, so nothing is racing the movement.

**Full evidence:** `artifacts/H-002-evidence-20260828.md`.

**Found while proving it, and more dangerous than H-002 was:** register
67 clamps at 32766, roughly eight revolutions of NET one-directional
travel. Past the clamp the servo stops moving in BOTH directions and
still reports a following error of about 2 - a movement that would
report VERIFIED and would not happen. A carousel that always takes the
shortest path to the next slot accumulates a full revolution every four
samples, so this is reached in ordinary service, not at the edge of it.
The driver folds the register back before it can happen, by passing
through position servo mode, which reseeds it from the absolute encoder
and moves nothing; the logical carousel angle is carried across
unchanged. `HW-B3-008` drives the register there and watches it fold.

**Now covered by:** `HW-B2-013` (the position changes when the carousel
moves), `HW-B2-014` (diagnostics does not claim more than it proves),
`HW-B3-006` (a re-sync reads exactly 0.0 deg at any raw count),
`HW-B3-007` (a held carousel is reported as a failure),
`HW-B3-008` (the trajectory register is folded before it clamps),
`HW-B8-002` (the RF-001 regression itself).

### H-003 — the AS7265x is ready within the configured integration time

`SENSOR_INTEGRATION_CYCLES = 100` and the driver waits
`cycles * 2.8 * 1.5 + 1` ms for data-ready.

**Software has verified:** that a sensor which never asserts ready is
timed out and named, that a partial read is refused, and that the lamps
are switched off afterwards in every path including the failing ones.

**Hardware must establish:** the real ready latency across all three
illuminations and a realistic temperature range.

### H-004 — the CP2102 survives repeated open cycles

`SerialLink.open()` drives DTR and RTS low before opening so the board
is not reset. This was measured once.

**Software has verified:** that the lines are set before `open()` and
stay low, and that the port is released on every exit path.

**Hardware must establish:** that a thousand open/close cycles do not
wedge the bridge, and that the board never resets during them. This is
also where **RF-002** belongs: `/dev/ttyUSB0` disappeared mid-request on
the bench and the electrical cause is unknown.

### H-005 — RESOLVED ON HARDWARE, 2026-08-28

`CAROUSEL_HALF_TURN_DEG` and the 4096-count assumption give 2048, and
that is right. Eight consecutive +512 steps moved the absolute position
from 3015 to 7111 - exactly +4096, one revolution - and four -1024
steps brought it back to 3015 exactly. There is no reduction between
the encoder and the counted position, so no angle in the firmware is
scaled by an unknown ratio.

What a plate-to-shaft reduction would still hide is not electrically
observable; `HW-B3-005` remains the protractor measurement that would
settle that, and it needs an operator.

### H-006 — backlash does not accumulate

**Software has verified:** 2000 simulated movements with no logical
drift.

**Hardware must establish:** whether physical position drifts after
repeated alternating movements, and whether a re-sync is needed after N
cycles.

---

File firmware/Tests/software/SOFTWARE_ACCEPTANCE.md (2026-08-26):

# Software Acceptance Record

> **SUPERSEDED BY PHASE A.3.** This file is the A.2 record and is kept
> as history. The current state of the software is in
> `SOFTWARE_ASSURANCE_REPORT.md`, with `SOFTWARE_FAULT_CATALOG.md`,
> `SOFTWARE_FAILURE_MATRIX.md` and `SOFTWARE_ASSUMPTIONS.md` beside it.
>
> A.3 found seven further defects — three of which would have been felt
> on the field — and the numbers below have all moved: 28 suites became
> 37, 2,366 checks became 3,188, and 23 mutations became 37.

**Date:** 2026-08-24
**Phase:** A.2 — final software closure before hardware verification
**Repository state:** uncommitted working tree; no commits, no pushes

---

## 1. Status

```
SOFTWARE ACCEPTANCE:  PASS
```

No known software-testable defect remains in the competition-relevant
system. Every defect found across the two campaigns is fixed and
regression-protected. Every remaining uncertainty is assigned to
hardware (`HARDWARE_VERIFICATION_PLAN.md`) or to offline tooling.

This is **not** a claim that the software is free of bugs. It is the
claim that we have tried hard to break it and can no longer do so
without hardware.

---

## 2. The numbers

| | |
| --- | --- |
| Suites | 28 |
| Checks | 2366 |
| Runs compared | 2, byte-identical |
| `BD/` after every run | 24 files, unchanged |
| Mutations attempted / killed | 23 / 23 |
| Statement + branch coverage | 71% |
| Third-party dependencies on the competition path | 1 (`pyserial`) |

Phase A ended at 22 suites and 1787 checks; A.2 added 6 suites and 579
checks, and closed the two coverage gaps the previous report named.

---

## 3. How to reproduce this result

```bash
python3 firmware/Tests/run_all.py                     # the campaign
python3 firmware/Tests/software/mutation.py           # does it have teeth
python3 firmware/Tests/software/coverage_report.py    # branch coverage
```

The first is the acceptance gate. The second and third are diagnostic
and are **not** part of it: `mutation.py` edits production files (and
restores them byte-for-byte, verified by hash), and
`coverage_report.py` needs `coverage.py`, which is a development
dependency and must never be needed to run the campaign.

---

## 4. Defects found and fixed

### Phase A.2 — the real Linux bench failures

These were observed with a rover on a desk, not imagined.

| ID | Severity | Defect | Fix |
| --- | --- | --- | --- |
| RF-001 | **P0** | A failed half turn reported `moved: False`, so the operator was told "carousel: nothing was moved" after a rotation they had just watched | The servo attaches motion evidence to every failure; the carousel derives a three-way verdict (`NOT_STARTED` / `MOVED` / `UNKNOWN`); the screen states which, and tells the operator to look at the mechanism |
| RF-002 | **P0** | `PORT_LOST` closed the link correctly, and the next `hardware_status()` killed the application with `RuntimeError("Link is not open")` | A closed link raises `PORT_CLOSED`, a `LinkError` — the language the 39 existing handlers already catch |
| RF-003 | **P1** | The same crash from the sensor test, on the second attempt | Same root cause; fixed by the same change |
| RF-004 | **P1** | Connection loss was handled as one failed call rather than an application state | Centralised in the one serial owner; every screen verified against a lost port |
| RF-005 | **P1** | A measurement failure could not be located in the sequence | The firmware names the stage (`PRECHECK` / `MOVE_TO_SCANNER` / `ACQUISITION`); the screen prints a different sentence for each |

### Phase A.2 — found by this campaign

| Severity | Defect | Fix |
| --- | --- | --- |
| **P1** | Request ids were seeded from `time.time()*1000 % 1000000`, which **wraps every 1000 seconds** — two clients started 17 minutes apart produced identical ids, and `wait_online` makes `ping` the first command of every session | A random 24-bit session nonce from `os.urandom` plus a counter: `<nonce>-<n>`. The firmware echoes it verbatim, so no protocol change |
| **P1** | Browsing a **migrated legacy record** crashed the records screen: three tables formatted `match.get("rank")` into `{:<4}`, and migrated `reference_matches` have no rank | `rank_of()`, matching the module's existing `score()`/`number()` discipline |
| **P1** | The measurement pre-flight "proved" the sensor from a cached flag, so a sensor that died since the last measurement passed and the carousel made the whole 180° journey before anyone found out | `ensure_ready(probe=True)` — one register read before anything moves |
| **P2** | `print_decision` formatted `candidate.get("evidence_level", "-")`, which returns `None` when the key is present and null — the same blind spot as `rank`, reachable from stored AnalysisRuns | `or "-"` |

### Phase A — carried forward

Stale-frame acceptance, NaN as a carousel angle, NaN on the wire, a full
disk crashing the client, the phantom in-memory Sample, RAW stored by
reference, `--help` rewriting DB3, the Linux port classification, three
names that did not exist, the bus scan losing the origin silently, and
non-finite values through `normalize()`. All fixed in Phase A; all still
regression-protected here.

---

## 5. Coverage

Measured with `coverage.py 7.15.4`, **branch mode**, over the suites
that execute production code.

Reported by class, because a single number cannot distinguish a
hardware-only branch from a forgotten one.

| Class | Closure |
| --- | --- |
| Mission-critical, software-testable | executed and asserted |
| Operator-reachable, software-testable | executed |
| Offline-only (`research/`, `tools/`, `Science/model_registry.py`) | imports, `--help`, no destructive execution |
| Hardware-only | listed in `HARDWARE_VERIFICATION_PLAN.md` |

Combined statement + branch coverage of the four production domains:
**71%** (9481 statements, 2850 branches). The figures that moved in
this campaign:

| Module | Before A.2 | After A.2 |
| --- | --- | --- |
| `PC/workflow/display.py` | 52% | **76%** |
| `PC/workflow/records.py` | 34% | **49%** |
| `PC/serial_link.py` | 85% | 85% |
| **Total** | 67% | **71%** |

`records.py` remains the lowest at 49% and that is the honest number.
What is now covered is every flow an operator reaches during and after
a mission: listing, opening, editing, renaming, deleting, importing,
the learning history, and a record migrated from the old schema. What
remains uncovered is the ground-truth labelling machinery -
`ask_material`, `ask_family`, `ask_mixture`, `ask_sample_context` -
which is a long branching interview used offline, after the
competition, to label observations for model training. It is
classified **OFFLINE_ONLY**: it cannot affect a measurement, a
carousel position or a saved spectrum.

### Classification of what remains uncovered

- **`Science/model_registry.py` — 0%, OFFLINE_ONLY.** It has **no
  callers anywhere**: only a mention in `Science/__init__.py`'s
  docstring. It is intentional API for offline model promotion (§50),
  not dead code from a removed architecture, and it is not on the
  mission path. Verified: it imports, it does not write on import, and
  its status vocabulary is coherent. Not removed — it is a documented
  future workflow, not an accident.
- **`ESP32/boot.py` — one line, deliberately does nothing.**
- **Defensive branches in the ESP32 drivers** that require an I²C or
  UART failure mode the fakes cannot produce (a half-written register,
  a frame corrupted in a specific byte). Listed as hardware items.
- **`research/`** — offline analysis and ERC planning. Verified for
  safe import and safe `--help`; branch coverage is not pursued.

---

## 6. Mutation verification

`mutation.py` applies 23 mutations to decisions that can cause an
operational failure, runs the suites that should notice, and restores
every file byte-for-byte.

The one survivor was a real finding: `Carousel.require_position` could
be turned into a no-op and the carousel state suite still passed,
because its assertion was `code != "OK"` rather than the exact code.
The assertion was strengthened to `POSITION_NOT_SYNCHRONIZED` and the
mutation now dies.

Two bugs in the harness itself were found and fixed the same way: a
text-mode restore that rewrote line endings (caught by its own hash
check), and multi-line patterns that stopped matching once the restore
was made byte-exact.

---

## 7. Exception audit

215 exception handlers in mission code (`PC`, `Science`, `BD`,
`ESP32`), of which 45 are broad (`except Exception`).

- **0** bare `except:` — enforced statically.
- **7** silent `except Exception: pass`, every one best-effort cleanup:
  releasing a port, clearing a buffer after a reset, switching lamps off
  in a `finally` beside a bare `raise`, and the last-resort attempt to
  tell the host a response could not be sent. Each is listed by name in
  `static/test_static_api.py`; a new one fails the suite and has to be
  justified in the same change that introduces it.
- **0** instances of the §16 pattern — a programming error assigned into
  a plausible-looking value. Every assigning handler records the failure
  into a field the operator sees.

The most important of the silent handlers is `sensor.acquire_one`: if
its lamp-off raised, it would **mask** the `SensorError` being
re-raised, and the operator would be told the lamp failed rather than
why the acquisition did.

---

## 8. Request identity

The question: can an answer to another question be accepted as the
answer to ours?

Two designs have already failed here — a counter from 1, and a
clock-seeded counter that wrapped every 1000 seconds. The current
design is `<24 random bits>-<counter>`, and a frame is accepted only
when the id matches, the frame carries `ok`, **and** the command name
matches.

`contracts/test_request_identity.py` proves the point that matters: not
that a collision is unlikely, but that a collision is **not sufficient**.
Every check there forges a matching id and asks whether the frame is
accepted anyway.

---

## 9. Reset and restart

`state_machine/test_reset_recovery.py` covers all four combinations of
PC and ESP32 restart, plus a reset at each point of a command.

The property enforced: **a position never survives a reset.** If the
firmware has forgotten where the carousel is, no PC-side memory may put
a slot number back on screen — the servo could have been turned by hand
while the board was down, and a remembered number is indistinguishable
from a measured one once displayed.

Also verified: boot banners and startup tracebacks are preserved for
diagnosis and are never mistaken for an answer; the device's retained
acquisition buffer is volatile, which is why RAW is persisted the
instant it arrives.

---

## 10. Data integrity

Every suite writes through `SandboxBD`, a temporary tree seeded from the
real reference data. `run_software.py` hashes every file under
`firmware/BD/` before and after the whole campaign and fails the run if
one byte moved — a check that does not depend on anybody remembering to
use the sandbox.

Verified across every campaign run in this phase: **BD/ unchanged.**

---

## 11. Test architecture

```
firmware/Tests/
├── run_all.py                 software only; refuses --hardware
├── software/
│   ├── run_software.py        the acceptance gate + BD/ hash guard
│   ├── mutation.py            does the suite have teeth (diagnostic)
│   ├── coverage_report.py     branch coverage (diagnostic)
│   ├── fakes/                 clock, serial port, ESP32, console, BD
│   ├── static/ unit/ contracts/ integration/ fault_injection/
│   ├── state_machine/ linux/ entrypoints/ data_integrity/
│   └── stress/ randomized/ regression/
└── hardware/
    ├── run_hardware.py        --port required, --move to turn anything
    ├── hardware_validation.py
    └── HARDWARE_VERIFICATION_PLAN.md
```

Mocking is at the lowest practical boundary: `serial.Serial`,
`machine.I2C`, `machine.UART`, the clock, the keyboard, and the
directory records live in. Everything above that line is production
code, including the ESP32 firmware — `LoopbackDevice` runs the real
`Protocol` dispatcher in-process.

---

## 12. What is still uncertain

No P0 or P1 software-testable risk is open.

Remaining uncertainty is hardware, and every item has an ID in
`HARDWARE_VERIFICATION_PLAN.md`:

- **H-002** is the one that matters. On the bench a carousel visibly
  rotated 180° while the encoder reported 2 counts. The software
  arithmetic is verified correct at all 4096 positions; **why the
  encoder and the operator disagreed is unknown and cannot be
  determined from software.**
- **H-001** — whether 15 counts is the right tolerance.
- **H-003** — real AS7265x ready latency.
- **H-004** — CP2102 reliability, and why `/dev/ttyUSB0` disappeared.
- **H-005** — whether a half turn is really 2048 counts on this
  mechanism. If there is a reduction, H-002 explains itself.
- **H-006** — physical backlash.

---

## 13. The acceptance question

> If the ESP32, ST3215, AS7265x and USB link behaved exactly according
> to the assumptions our software interfaces represent, is there any
> known software reason the competition workflow would fail, corrupt
> data, lose logical state, accept false success or become
> unrecoverable?

**No.** The evidence is the campaign: every command executed against the
real firmware; every screen entered and abused; every external operation
failed on purpose; both state machines walked exhaustively; all four
restart combinations; a forged-collision attack on request identity;
23 mutations of safety-critical decisions, all killed; and the archive
provably untouched.

The honest qualifier: this holds **given the assumptions**. H-002 is
evidence that at least one of them was wrong on real hardware, and the
software could not have known.

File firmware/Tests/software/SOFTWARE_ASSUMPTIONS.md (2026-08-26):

# Software Assumption Register

**Phase:** A.3
**Date:** 2026-08-25

Everything the software takes on faith, stated once, with an ID and an
owner. Nothing here can be settled by running a test on this machine —
that is what makes it an assumption rather than a fact.

Two families:

- **H-nnn** — hardware assumptions. Each maps to a section of
  `firmware/Tests/hardware/HARDWARE_VERIFICATION_PLAN.md`.
- **A-nnn** — environment and platform assumptions. Each is checked as
  far as software can check it, and the residue is stated.

The rule for the whole register: if the assumption is wrong, the entry
says **what breaks**. An assumption whose consequences are not written
down cannot be prioritised on the bench.

---

## H — hardware assumptions

### H-001 — the ST3215 settles within 15 counts

**Assumed:** a completed movement leaves the shaft within
`ST3215_POSITION_TOLERANCE` (15 counts, ≈ 1.3°) of its goal.

**Why software cannot settle it:** the number is a property of the
servo's control loop under this mechanism's inertia and friction.

**If wrong:** too tight and every good movement is reported as a
`SERVO_POSITION_MISMATCH`; too loose and a slot that stopped short is
accepted, so the scanner reads the edge of a well.

**Verified by:** fifty identical slot movements, recording every
`position_error` — `HARDWARE_VERIFICATION_PLAN.md` §servo.

---

### H-002 — the encoder tracks the mechanism

**Assumed:** the position the ST3215 reports corresponds to where the
shaft physically is.

**Why software cannot settle it:** the software arithmetic is verified
correct at all 4096 positions. Whether the number describes reality is
electrical and mechanical.

**Status:** **known to have been violated once.** On the bench a
carousel visibly rotated 180° while the encoder reported 2 counts.

**If wrong:** every position decision the firmware makes is built on a
number that does not describe the mechanism. This is the single most
important open item in the project.

**Verified by:** free-shaft relative move with a protractor, then the
same with the carousel attached — `HARDWARE_VERIFICATION_PLAN.md`
§servo (2,3,4,5).

---

### H-003 — the AS7265x is ready within the configured time

**Assumed:** the sensor raises data-ready within the integration time
plus `ACQUISITION_RESPONSE_SETTLE_MS`.

**If wrong:** either every acquisition times out, or — worse — a read
returns the *previous* conversion and the spectrum belongs to the last
illumination.

**Verified by:** data-ready latency across all three illuminations,
fifty cold initializations — `HARDWARE_VERIFICATION_PLAN.md` §sensor.

---

### H-004 — the CP2102 link is electrically stable

**Assumed:** the USB bridge stays enumerated for the length of a
mission, and `/dev/ttyUSB0` does not disappear.

**Status:** **known to have been violated once.** The node vanished
mid-session on the Linux bench.

**Software response, already built:** every errno that a vanished tty
can raise is classified as `PORT_LOST` at all four pySerial entry
points, the link closes itself, and every later command is refused as
`PORT_CLOSED` rather than crashing — `LNX-001`, `LNX-002`.

**If wrong again:** the mission is interrupted but not corrupted. The
software now survives it; what it cannot do is prevent it.

**Verified by:** repeated open/close ×1000 checking for a boot banner
each time — `HARDWARE_VERIFICATION_PLAN.md` §link.

---

### H-005 — a half turn is 2048 counts on this mechanism

**Assumed:** no reduction between the servo output and the carousel, so
4096 counts is one carousel revolution.

**If wrong:** every slot angle is wrong by the reduction ratio — and
H-002 explains itself.

**Verified by:** the same protractor test with the carousel attached —
`HARDWARE_VERIFICATION_PLAN.md` §servo (4).

---

### H-006 — backlash does not accumulate

**Assumed:** repeated load ↔ scan transfers do not drift.

**If wrong:** the carousel walks away from its origin over a
competition day, and the drift is invisible until a sample misses the
scanner.

**Verified by:** alternating movements ×200, measuring accumulated
offset — `HARDWARE_VERIFICATION_PLAN.md` §servo.

---

### H-007 — the ESP32 has enough heap during a real acquisition

**Assumed:** the device can build and send a full triad response
without fragmenting its heap past recovery.

**Why software cannot settle it:** CPython's allocator is nothing like
MicroPython's on a 520 KB device, and fragmentation depends on the real
allocation history.

**Software response, already built:** `MemoryError` is injected at the
firmware's real allocation boundaries and the guards are proven to work
— a response that cannot be joined is written in pieces, and any
handler that raises still produces a well-formed error frame naming
`MemoryError` (`MEM-009`, `MEM-010`).

**What is NOT claimed:** that the device has sufficient RAM. Only that
the code does the right thing when it does not.

**Verified by:** heap and endurance measurement on the device —
**to be added to the hardware plan.**

---

### H-008 — opening the port does not reset the board

**Assumed:** with DTR and RTS driven low before `open()`, the auto-reset
circuit does not fire.

**Status:** measured once on this development board, and the software is
built on that measurement.

**If wrong:** starting the client reboots an instrument that may be
holding a hand-synchronized carousel position. The software would
notice — the position comes back invalid — so this costs a
resynchronization, not data.

**Verified by:** open the port fifty times, checking for a boot banner —
`HARDWARE_VERIFICATION_PLAN.md` §link.

---

### H-009 — the illumination named RED is the IR lamp

**Assumed:** the requirement document's "RED" illuminator is the
hardware's IR channel. The board has white, UV and IR, and no red
illuminator.

**Why software cannot settle it:** it is a naming question about a
physical part.

**If wrong:** the spectra are correct and the *label* on one third of
them is wrong, which would misdescribe every stored measurement.

**Verified by:** confirming the fitted part against the schematic —
**to be added to the hardware plan.**

---

## A — environment and platform assumptions

### A-001 — the competition interpreter is CPython 3.8 or newer

**Checked in software:** no `match`/`case` anywhere in the mission tree;
every module parses and imports under the development interpreter
(3.14). `linux/test_linux_runtime.py`.

**Residue:** the tests here run on 3.14. The Linux main computer's
interpreter has **not** been pinned in this repository, and a syntax or
stdlib difference between 3.8 and 3.14 would not be caught by this
campaign.

**Action before the competition:** run
`python3 firmware/Tests/run_all.py` **on the rover's own machine**, with
its own interpreter. That single run converts this assumption into a
fact and needs no hardware attached.

---

### A-002 — `pyserial` is the only third-party runtime dependency

**Checked in software:** every import in `PC/`, `Science/` and `BD/` is
resolved against the standard library; exactly one third-party name
appears, and only under `PC/`. `linux/test_linux_runtime.py`.

**Residue:** none. This one is mechanically proven.

---

### A-003 — a missing `pyserial` is diagnosable

**Checked in software:** the message names the package, the exact `pip`
command, and `sys.executable` rather than a launcher that only exists on
Windows.

**Residue:** none.

---

### A-004 — `sqlite3` is present in the deployed Python

**Assumed:** the standard-library `sqlite3` module is importable.

**Why it matters:** `BD/decision_learning.py` imports it at module
level, and `workflow/session.py` imports that module at *its* top level.
The learning layer is designed to be optional at **runtime** — a
missing or corrupt database file is survivable and reported — but a
missing `sqlite3` **module** would fail at import, before any guard.

**Checked in software:** the runtime-optionality claim is tested (a
missing, empty and corrupt learning database are all survivable). The
module's presence is not, because it is present on every mainstream
build.

**If wrong:** the client does not start at all, with an `ImportError`
naming `sqlite3`.

**Action before the competition:** covered by the A-001 action — a
single run on the rover's own machine proves it.

---

### A-005 — the archive directory is writable and on one filesystem

**Assumed:** `firmware/BD/samples/` is writable, and the temporary file
`_write_json` creates lands on the same filesystem as the archive, so
`os.replace` is atomic.

**Checked in software:** the temporary is created with
`dir=path.parent`, which guarantees the same directory. Every way the
write can fail is tested (`FS-001`…`FS-010`).

**Residue:** atomicity of `rename(2)` is a filesystem guarantee. It
holds on ext4, xfs and btrfs; it does **not** hold across a mount
boundary, which the `dir=` argument prevents.

---

### A-006 — the terminal encoding may be anything

**Assumed:** stdout may be UTF-8, cp1252, latin-1 or ASCII.

**Checked in software:** the client reconfigures stdout, stderr and
stdin to a non-raising error handler at startup, and a record with
Czech text is printed on all four encodings without raising.
`LNX-013`.

**Residue:** none for correctness. On a non-UTF-8 terminal some
characters render as `\uXXXX` escapes; the **archive** is unaffected and
keeps real UTF-8.

---

### A-007 — the wall clock may be wrong; the monotonic clock may not

**Assumed:** `time.monotonic()` does not go backwards.

**Checked in software:** every timeout in the mission tree is built on
`time.monotonic()`; `time.time()` appears in mission code only inside a
comment explaining why it is not used. Wall-clock jumps of ±2 hours, to
1970 and 1000 days forward are all driven, and no timeout is disturbed.
`LNX-014`, `LNX-015`.

**Residue:** none. `time.monotonic()` is guaranteed monotonic by the
language.

---

### A-008 — one client, one port, one archive

**Assumed:** exactly one operator client runs against the module.

**Checked in software:** the port is opened with `exclusive = True`, so
a second client is refused with `PORT_BUSY`. Concurrent archive writers
are **not supported**, and the exclusive open is what makes a second
mission client impossible in the first place. `LNX-005`, `LNX-006`.

**Residue:** two processes could still both open the archive *without*
the port — for example the client and an offline analysis script. That
is last-writer-wins, the file is never corrupt, and it is documented
rather than defended.

---

### A-009 — the repository is deployed as checked out

**Assumed:** every path resolves from `__file__`, so the working
directory and `PYTHONPATH` do not change what the program reads or
writes.

**Checked in software:** no mission module reads any environment
variable; entry points resolve their own location; every suite resolves
the tree by directory **name** rather than by counting parents, and a
regression test enforces it. `LNX-016`.

**Residue:** the repository must be checked out with its case preserved.
`linux/test_linux.py` checks that no two files differ only by case and
that no import differs from its file only by case.

---

### A-010 — the firmware on the device matches this repository

**Assumed:** the `.mpy` files on the ESP32 were built from the `ESP32/`
tree in this checkout.

**Why software cannot settle it:** the host cannot see what is flashed.

**Partially checked:** every response records a firmware version, and
that version is stored on every Measurement, so a mismatch is
detectable *after the fact* in the archive.

**Action before the competition:** redeploy with `tools/device.py`
immediately before the run, and confirm the version reported by `ping`.

---

## Ownership summary — A.3 §121

| Category | Count | Owner |
| --- | --- | --- |
| Hardware, with a plan section | 9 (H-001…H-009) | Phase B, on the bench |
| Environment, mechanically proven | 6 (A-002, A-003, A-005, A-006, A-007, A-009) | Closed |
| Environment, needs one run on the rover's machine | 2 (A-001, A-004) | **Before the competition, no hardware needed** |
| Environment, documented design decisions | 2 (A-008, A-010) | Intentional |

Nothing in this register is unowned, and nothing is marked
`UNKNOWN`, `TODO` or `MAYBE`.

Two of these — A-001 and A-004 — are worth stating plainly, because
they are the only items in the whole campaign that could be closed
today and have not been: **the test campaign has never been run on the
Linux machine the rover actually uses.** It needs no hardware, no
carousel and no sensor. It is one command.

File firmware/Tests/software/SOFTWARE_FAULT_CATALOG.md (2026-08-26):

# Software Fault Catalogue

**Phase:** A.3 — final adversarial campaign before hardware verification
**Date:** 2026-08-25
**Scope:** every software failure class that can affect the competition
runtime of the Freya science module.

---

## How to read this

Every fault class has an ID, a trigger, the behaviour required of the
software, the test that proves it, and exactly one classification:

| Classification | Meaning |
| --- | --- |
| `VERIFIED` | A software test drives the fault and asserts the required behaviour. |
| `HARDWARE_ONLY` | The fault cannot be produced without real silicon. Assigned to `HARDWARE_VERIFICATION_PLAN.md`. |
| `OFFLINE_ONLY` | Reachable only from post-competition tooling; cannot affect a measurement, a carousel position or a saved spectrum. |
| `NOT_APPLICABLE` | The architecture makes the fault impossible, and the reason is stated. |
| `OPEN_BLOCKER` | Known, mission-relevant, and not closed. **Must be zero at freeze.** |

```
VERIFIED         96
HARDWARE_ONLY    14
OFFLINE_ONLY      4
NOT_APPLICABLE    9
OPEN_BLOCKER      0
                ---
total           123
```

Test names are relative to `firmware/Tests/software/`.

---

## SER — the serial transport

| ID | Trigger | Required behaviour | Test | Status |
| --- | --- | --- | --- | --- |
| SER-001 | Port does not exist | `PORT_NOT_FOUND`, names the cable | `linux/test_linux.py` | VERIFIED |
| SER-002 | Port held by another program | `PORT_BUSY`, names the other program, does **not** mention groups | `linux/test_linux.py`, `linux/test_linux_runtime.py` | VERIFIED |
| SER-003 | Account not in the serial group | `PORT_DENIED`, names `dialout` and `usermod`, says re-login is needed | `linux/test_linux.py` | VERIFIED |
| SER-004 | Port opens, nothing answers | `PROTOCOL_TIMEOUT` with the console output attached | `fault_injection/test_serial_faults.py` | VERIFIED |
| SER-005 | Board sitting at the MicroPython REPL | `DEVICE_AT_REPL`, immediately, without waiting out the timeout | `fault_injection/test_serial_faults.py` | VERIFIED |
| SER-006 | Frame damaged in transit | `MALFORMED_RESPONSE`; retried only for pure reads | `fault_injection/test_serial_faults.py` | VERIFIED |
| SER-007 | Rubbish in front of an intact frame | Salvaged, counted in `salvaged_frames` | `fault_injection/test_serial_faults.py` | VERIFIED |
| SER-008 | Device disappears mid-request | `PORT_LOST`, link closes itself, every later command is `PORT_CLOSED` | `regression/test_linux_bench.py` | VERIFIED |
| SER-009 | Non-finite value in a payload | `INVALID_REQUEST` **before** anything is written | `unit/test_prompts.py` | VERIFIED |
| SER-010 | Firmware answers `ok: false` | `DeviceError` carrying the firmware's own code | `contracts/test_pc_firmware.py` | VERIFIED |
| SER-011 | Answer to a **different** request arrives | Not accepted; `stale_frames` incremented | `fault_injection/test_protocol_limits.py` | VERIFIED |
| SER-012 | Our own request echoed back | Not accepted — a response must carry `ok` | `fault_injection/test_protocol_limits.py` | VERIFIED |
| SER-013 | Forged frame with a colliding request id | Rejected unless the command also matches | `contracts/test_request_identity.py` | VERIFIED |
| SER-014 | Echo storm, then boot text, then the real answer | The real answer is found; echoes kept as noise | `fault_injection/test_protocol_limits.py` | VERIFIED |
| SER-015 | Echo storm with **no** answer behind it | `PROTOCOL_TIMEOUT` or `DEVICE_AT_REPL`, never success | `fault_injection/test_protocol_limits.py` | VERIFIED |
| SER-016 | Unsolicited but valid frames | Ignored; a real answer behind them still returns | `fault_injection/test_protocol_limits.py` | VERIFIED |
| SER-017 | Lost acknowledgement of a **movement** | Never retried — a relative move would happen twice | `fault_injection/test_serial_faults.py` | VERIFIED |
| SER-018 | Opening the port resets the board | DTR/RTS driven low **before** `open()` | `integration/test_pc.py` | VERIFIED |
| SER-019 | Real DTR/RTS electrical behaviour | — | `HARDWARE_VERIFICATION_PLAN.md` H-004 | HARDWARE_ONLY |
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

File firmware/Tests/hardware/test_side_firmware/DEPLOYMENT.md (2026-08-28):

# Deploying the diagnostic agent

> ## This is not competition firmware
>
> `diagnostic_agent.py` exists to answer three questions the shipped
> firmware cannot: what bytes the ST3215 actually returned, what its
> full telemetry says, and which addresses answer on the I2C bus right
> now. It unblocks `HW-B2-006`, `HW-B3-004` and `HW-B6-001`.
>
> **It has never been deployed.** Those three tests stay `NOT_RUN` and
> `BLOCKED` until it has been, on real hardware, by a human following
> this page.

---
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

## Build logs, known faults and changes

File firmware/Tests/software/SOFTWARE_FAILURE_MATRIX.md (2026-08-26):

# Software Failure Coverage Matrix

**Phase:** A.3
**Date:** 2026-08-25

Every mission-relevant component against every way an external operation
can fail. This is a checklist, not decoration: a blank mission-relevant
cell is a gap, and there are none.

---

## Legend

| Symbol | Meaning |
| --- | --- |
| **T** | Tested — a deterministic software test drives this cell |
| **P** | Property / model / fuzz — driven by a generator, invariants asserted |
| **S** | Static — proven by parsing the source, not by running it |
| **H** | Hardware only — needs real silicon; carries an H-number |
| **—** | Not applicable, with the reason given under the table |

Column meanings:

- **Success** — the operation works
- **Timeout** — no answer within the bound
- **Exception** — the operation raises
- **Malformed** — the answer arrives and is wrong
- **Disconnect** — the far end goes away mid-operation
- **Resource** — memory, descriptors, disk or inodes give out
- **Recovery** — the operator retries, reconnects or restarts

---

## 1. SerialLink

| Operation | Success | Timeout | Exception | Malformed | Disconnect | Resource | Recovery |
| --- | :-: | :-: | :-: | :-: | :-: | :-: | :-: |
| `open()` | T | — ¹ | T | — ¹ | T | T ² | T |
| `wait_online()` | T | T | T | T | T | — ³ | T |
| `request()` | T | T | T | T | T | T | T |
| `_read_response()` | T | T | T | T | T | T | T |
| framing / resync | T | T | T | T | T | T | T |
| request-id match | T | — ⁴ | — ⁴ | T | T | — ⁴ | T |
| `close()` | T | — ⁵ | T | — ⁵ | T | — ⁵ | T |
| `hard_reset()` | T | — ⁵ | T | — ⁵ | T | — ⁵ | H (H-004) |

¹ `open()` either returns or raises; there is no bounded wait inside it.
² `os.urandom` failure at construction — FS/`SER-032`.
³ `wait_online` only pings; it allocates nothing that can fail alone.
⁴ Pure comparison over an already-parsed dict; it cannot time out, raise or exhaust anything.
⁵ `close()` is documented never to raise and swallows everything.

---

## 2. ESP32 protocol (firmware side)

| Operation | Success | Timeout | Exception | Malformed | Disconnect | Resource | Recovery |
| --- | :-: | :-: | :-: | :-: | :-: | :-: | :-: |
| `read_command()` | T | — ¹ | T | T | T | H ² | T |
| `process_line()` | T | — ¹ | T | T | — ³ | T | T |
| `dispatch()` | T | — ¹ | T | T | — ³ | T | T |
| argument validation | T | — ¹ | T | T | — ³ | — ⁴ | T |
| `send_json()` | T | — ¹ | T | T | T | T | T |
| `_ChunkSink` | T | — ¹ | T | — ⁴ | T | T | T |
| `make_json_safe()` | T | — ¹ | T | T | — ³ | T | T |
| `serve_forever()` | T | — ¹ | T | T | T | T | T |

¹ The firmware blocks on `readline`; it has no deadline of its own — the PC owns every timeout.
² Unbounded accumulation before the length check — `PROTO-014`, hardware-only in practice because only the PC writes to that stdin.
³ The firmware cannot observe the host disconnecting; it simply never receives another line.
⁴ Pure function over already-parsed values.

---

## 3. Servo abstraction

| Operation | Success | Timeout | Exception | Malformed | Disconnect | Resource | Recovery |
| --- | :-: | :-: | :-: | :-: | :-: | :-: | :-: |
| `connect()` | T | T | T | T | T | — ¹ | T |
| `read_word()` / `write_word()` | T | T | T | T | T | — ¹ | T |
| position read | T | T | T | T | T | — ¹ | T |
| `move_to()` | T | T | T | T | T | — ¹ | T |
| tolerance verdict | T | T | T | T | T | — ¹ | T |
| bus scan | T | T | T | T | T | — ¹ | T |
| checksum / framing | T | T | T | T | T | — ¹ | T |
| **encoder vs shaft agreement** | H (H-002) | H | H | H | H | — | H |
| **settling within tolerance** | H (H-001) | H | H | H | H | — | H |
| **backlash** | H (H-006) | — | — | — | — | — | H |

¹ The servo driver allocates nothing per operation beyond small fixed buffers; heap pressure on the device is `MEM-011` / H-005.

---

## 4. Sensor abstraction

| Operation | Success | Timeout | Exception | Malformed | Disconnect | Resource | Recovery |
| --- | :-: | :-: | :-: | :-: | :-: | :-: | :-: |
| `bring_up()` | T | T | T | T | T | T | T |
| `ensure_ready()` | T | T | T | T | T | T | T |
| virtual register read | T | T | T | T | T | — ¹ | T |
| `acquire_one()` | T | T | T | T | T | T | T |
| `acquire_triad()` | T | T | T | T | T | T | T |
| lamp on / off | T | T | T | T | T | — ¹ | T |
| channel validation | T | — ¹ | T | T | — ¹ | — ¹ | T |
| **real data-ready latency** | H (H-003) | H | — | — | — | — | H |
| **half-written I²C register** | H | H | H | H | — | — | H |

¹ Register-level operations are fixed-size and synchronous.

---

## 5. Carousel workflow

| Operation | Success | Timeout | Exception | Malformed | Disconnect | Resource | Recovery |
| --- | :-: | :-: | :-: | :-: | :-: | :-: | :-: |
| `sync_position` | T | T | T | T | T | — ¹ | T |
| `select_slot` | T | T | T | T | T | — ¹ | T |
| `move_slots` | T | T | T | T | T | — ¹ | T |
| `fine_adjust` | T | T | T | T | T | — ¹ | T |
| position invalidation | T/P | T | T | T | T | — ¹ | T |
| phase derivation | T/P | — ¹ | T | T | — ¹ | — ¹ | T |
| reset → position lost | T/P | T | T | T | T | — ¹ | T |
| `connect_servo` → invalidate | T/P | T | T | T | T | — ¹ | T |

¹ Carousel state is a handful of integers; there is nothing here to exhaust.

---

## 6. Measurement workflow

| Operation | Success | Timeout | Exception | Malformed | Disconnect | Resource | Recovery |
| --- | :-: | :-: | :-: | :-: | :-: | :-: | :-: |
| pre-flight refusals | T | T | T | T | T | T | T |
| sensor probe before moving | T | T | T | T | T | T | T |
| move to scanner | T | T | T | T | T | — | T |
| acquisition | T | T | T | T | T | T | T |
| **persist RAW** | T | — ¹ | T | T | — ¹ | T | T |
| analysis | T | — ¹ | T | T | — ¹ | T | T |
| persist AnalysisRun | T | — ¹ | T | T | — ¹ | T | T |
| conclusion update | T | — ¹ | T | T | — ¹ | T | T |
| return move | T | T | T | T | T | — | T |
| stage naming on failure | T | T | T | T | T | T | T |
| Ctrl+C at each stage | T | — | T | — | T | T | T |

¹ Local operations with no wire and no deadline.

---

## 7. Science pipeline

| Operation | Success | Timeout | Exception | Malformed | Disconnect | Resource | Recovery |
| --- | :-: | :-: | :-: | :-: | :-: | :-: | :-: |
| `dark_correct` | T/P | — ¹ | T | T/P | — ¹ | T | T |
| `normalize` | T/P | — ¹ | T | T/P | — ¹ | T | T |
| `build_representations` | T/P | — ¹ | T | T/P | — ¹ | T | T |
| metrics (all seven) | T/P | — ¹ | T | T/P | — ¹ | T | T |
| `compare_library` | T/P | — ¹ | T | T/P | — ¹ | T | T |
| quality report | T/P | — ¹ | T | T/P | — ¹ | T | T |
| decision | T/P | — ¹ | T | T/P | — ¹ | T | T |
| `analyze()` end to end | T | — ¹ | T | T | — ¹ | T | T |

¹ Pure arithmetic. There is no external operation to time out or disconnect.

---

## 8. Sample persistence

| Operation | Success | Timeout | Exception | Malformed | Disconnect | Resource | Recovery |
| --- | :-: | :-: | :-: | :-: | :-: | :-: | :-: |
| `load()` | T | — ¹ | T | T | — ¹ | T | T |
| schema migration | T | — ¹ | T | T | — ¹ | T | T |
| `create()` | T | — ¹ | T | T | — ¹ | T | T |
| `set_state()` | T | — ¹ | T | T | — ¹ | T | T |
| `add_measurement()` | T | — ¹ | T | T | — ¹ | T | T |
| `add_analysis_run()` | T | — ¹ | T | T | — ¹ | T | T |
| `rename()` / `delete()` | T | — ¹ | T | T | — ¹ | T | T |
| `_write_json()` — mkdir | T | — ¹ | T | — ² | — ¹ | T | T |
| `_write_json()` — mkstemp | T | — ¹ | T | — ² | — ¹ | T | T |
| `_write_json()` — write | T | — ¹ | T | — ² | — ¹ | T | T |
| `_write_json()` — fsync | T | — ¹ | T | — ² | — ¹ | T | T |
| `_write_json()` — replace | T | — ¹ | T | — ² | — ¹ | T | T |
| rollback on failure | T | — ¹ | T | — ² | — ¹ | T | T |
| orphan temp files | T | — ¹ | T | T | — ¹ | T | T |

¹ Local filesystem operations; no deadline, no remote end.
² A write cannot produce a malformed result — it either lands atomically or does not land.

---

## 9. Calibration persistence

| Operation | Success | Timeout | Exception | Malformed | Disconnect | Resource | Recovery |
| --- | :-: | :-: | :-: | :-: | :-: | :-: | :-: |
| load library | T | — | T | T | — | T | T |
| migrate schema | T | — | T | T | — | T | T |
| select active | T | — | T | T | — | T | T |
| save new calibration | T | — | T | T | — | T | T |
| legacy calibration immutability | T/S | — | T | T | — | — | T |
| missing calibration at startup | T | — | T | T | — | T | T |

---

## 10. Records browser

| Operation | Success | Timeout | Exception | Malformed | Disconnect | Resource | Recovery |
| --- | :-: | :-: | :-: | :-: | :-: | :-: | :-: |
| list samples | T | — | T | T | T | T | T |
| open a record | T | — | T | T | T | T | T |
| migrated legacy record | T | — | T | T | T | T | T |
| rename / delete | T | — | T | T | T | T | T |
| import | T | — | T | T | T | T | T |
| sync ESP32 acquisitions | T | T | T | T | T | T | T |
| learning history | T | — | T | T | T | T | T |
| ground-truth labelling | — ¹ | — | — | — | — | — | — |

¹ `OFFLINE_ONLY`. A long branching interview used after the competition to label observations for training; it cannot affect a measurement, a carousel position or a saved spectrum. `SCI-019`.

---

## 11. Configuration

| Source | Missing | Empty | Truncated | Malformed | Wrong schema | Wrong type | Out of range | Unknown field |
| --- | :-: | :-: | :-: | :-: | :-: | :-: | :-: | :-: |
| sample archive | T | T | T | T | T | T | T | T |
| calibration library | T | T | T | T | T | T | T | T |
| acquisition profiles | T | T | T | T | T | T | T | T |
| DB1 / DB2 / DB3 | T | T | T | T | T | T | T | T |
| learning database | T | T | T | T | T | T | T | T |
| `ESP32/config.py` | S ¹ | S ¹ | S ¹ | S ¹ | S ¹ | S ¹ | S ¹ | S ¹ |
| `Science/config.py` | S ¹ | S ¹ | S ¹ | S ¹ | S ¹ | S ¹ | S ¹ | S ¹ |
| `BD/config.py` | S ¹ | S ¹ | S ¹ | S ¹ | S ¹ | S ¹ | S ¹ | S ¹ |

¹ These are **Python modules deployed with the code**, not data files read at runtime. A malformed one is a syntax error at import, caught by the compile check in the acceptance sequence and by `entrypoints/test_entrypoints.py`. They cannot be corrupted independently of the firmware they ship with.

### Extreme configuration values — A.3 §21

| Value | Rejected where | Test |
| --- | --- | --- |
| negative / zero timeout | argparse `type=float`, then bounded waits | `entrypoints/test_entrypoints.py` |
| huge timeout | Accepted; the operator waits. Documented, not refused | `entrypoints/test_entrypoints.py` |
| invalid slot | firmware `_require_slot` | `fault_injection/test_firmware_faults.py` |
| slot of the wrong type | firmware `(TypeError, ValueError)` | `fault_injection/test_firmware_faults.py` |
| repeats outside 1…`MAX_REPEATS` | firmware bounds check | `fault_injection/test_firmware_faults.py` |
| fine adjust beyond `MAX_FINE_ADJUST_DEG` | firmware limit | `integration/test_esp32.py` |
| NaN / infinity as an angle | host prompt, before the wire | `unit/test_prompts.py` |
| invalid servo id / mode | firmware validation | `fault_injection/test_firmware_faults.py` |
| invalid baud | pySerial, classified as `PORT_OPEN_FAILED` | `linux/test_linux.py` |
| wrong channel count | Science validation | `unit/test_numeric_edges.py` |

---

## 12. CLI and startup

| Operation | Success | Bad input | Exception | Resource | Recovery |
| --- | :-: | :-: | :-: | :-: | :-: |
| argument parsing | T | T | T | — | T |
| `--help` | T | T | T | — | — |
| `--command` one-shot | T | T | T | T | T |
| `--payload` JSON | T | T | T | T | T |
| missing `pyserial` | T | — | T | — | T |
| `os.urandom` failure | — | — | T | T | T |
| console encoding | T | T | T | — | T |
| import side effects | S | S | S | — | — |
| clean shutdown (`q`) | T | T | T | — | T |
| EOF shutdown (Ctrl+D) | T | T | T | — | T |
| Ctrl+C shutdown | T | T | T | — | T |

---

## 13. Operation × fault matrices — A.3 §73–§76

### 13.1 Operation × ESP32 reset

| Operation | Before | During | After state change | Before response | After response |
| --- | :-: | :-: | :-: | :-: | :-: |
| sync | T | T | T | T | T |
| move | T | T | T | T | T |
| sensor test | T | T | T | T | T |
| measure | T | T | T | T | T |
| calibration | T | T | T | T | T |
| LED test | T | T | T | T | T |

Outcome in every cell: the position is invalid afterwards, and no PC-side memory restores it.

### 13.2 Operation × PORT_LOST

| Operation | Before | During | After state change | Before response | After response |
| --- | :-: | :-: | :-: | :-: | :-: |
| sync | T | T | T | T | T |
| move | T | T | T | T | T |
| sensor test | T | T | T | T | T |
| measure | T | T | T | T | T |
| calibration | T | T | T | T | T |
| LED test | T | T | T | T | T |

Outcome: `PORT_LOST`, the link closes itself, every later command is `PORT_CLOSED`, and the client stays alive.

### 13.3 Operation × operator abort

| Operation | Before | During acquisition | After acquisition | During save | During return |
| --- | :-: | :-: | :-: | :-: | :-: |
| measure | T | T | T | T | T |
| move | T | T | T | — ¹ | T |
| calibration | T | T | T | T | — ¹ |
| records | T | — ¹ | T | T | — ¹ |

¹ No such stage exists for that operation.

### 13.4 Operation × save failure

| Operation | ENOSPC | EROFS | ENOENT | EMFILE | MemoryError |
| --- | :-: | :-: | :-: | :-: | :-: |
| prepare a sample | T | T | T | T | T |
| confirm loaded | T | T | T | T | T |
| measure | T | T | T | T | T |
| clear slot | T | T | T | T | T |
| records browser | T | T | T | T | T |
| sync ESP32 acquisitions | T | T | T | T | T |
| carousel calibration | T | T | T | T | T |
| resync | T | T | T | T | T |
| sensor test | T | T | T | T | T |
| choose slot | T | T | T | T | T |

40 screen × failure combinations, driven in `integration/test_screens_failing.py`. In every one: no crash, the archive is byte-identical, and nothing prints a success it did not achieve.

---

## Gaps

**None that are mission-relevant and software-testable.**

Every `H` cell carries an H-number in
`firmware/Tests/hardware/HARDWARE_VERIFICATION_PLAN.md`. Every `—` cell
has its reason in a footnote directly beneath its table. There is no
cell in this document that is blank, unexplained, or marked "to do".

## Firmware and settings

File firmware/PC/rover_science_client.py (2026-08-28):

#!/usr/bin/env python3
"""
Freya science module - main computer application.

The operator interface and the mission controller. This program owns
the workflow, the Sample lifecycle and the orchestration of everything
else. It talks to three things and confuses none of them:

    PC  ->  serial  ->  ESP32      hardware: carousel and RAW spectra
    PC  ->  import  ->  Science    the mathematics and the decision
    PC  ->  import  ->  BD         calibration, DB1/DB2/DB3, records

The ESP32 never learns what a sample resembles. Science never learns
that a serial port exists. BD never learns either.

WHAT THIS FILE IS

The entry point, and nothing else: parse the arguments, open exactly
one serial port, hand it to the workflow, and close it on every path
out. The screens live in workflow/, the transport in serial_link.py,
and no scientific arithmetic lives anywhere on this side at all - if a
number appears on screen, Science computed it.

    python3 firmware/PC/rover_science_client.py --port /dev/ttyUSB0
    py      firmware/PC/rover_science_client.py --port COM4

    python3 firmware/PC/rover_science_client.py --port /dev/ttyUSB0 \
            --command ping --verbose

The first line of each pair is the Linux main computer, the second the
Windows bench. Forward slashes work on both. If Linux answers
PORT_DENIED, the account is not in the serial group - the error says
which command fixes it.

RUN IT FROM THE REPOSITORY ROOT. Every path this program needs is
resolved from __file__, so the working directory does not change what
it reads or writes - but the SCRIPT path on the command line is
resolved by the shell, and `py rover_science_client.py` from somewhere
else is a missing file, not a missing COM port.
"""

import argparse
import json
import sys
from pathlib import Path

# BD and Science are siblings of this directory. Putting the project
# root on the path means the application runs from anywhere without any
# PYTHONPATH setup, and every import below says which layer it came
# from.
PC_DIR = Path(__file__).resolve().parent
PROJECT_ROOT = PC_DIR.parent

for _path in (str(PROJECT_ROOT), str(PC_DIR)):
    if _path not in sys.path:
        sys.path.insert(0, _path)

import serial_link                                          # noqa: E402
from serial_link import (                                   # noqa: E402
    CONNECT_TIMEOUT,
    DEFAULT_BAUDRATE,
    DEFAULT_TIMEOUT,
    DeviceError,
    LinkError,
    SerialLink,
    utc_timestamp,
)
from workflow import status as ui_status                     # noqa: E402
from workflow.prompts import OperatorGone                    # noqa: E402
from workflow.screen import interactive                     # noqa: E402


def preflight(link, save_to=None):
    """
    Read-only bench check: what is connected, and is it healthy?

    THE FIRST THING TO RUN AFTER PLUGGING THE MODULE IN, and the thing
    to run again when something goes strange. It answers, in one pass:

        which device this is, and what firmware it runs
        whether this client and that firmware agree on the protocol
        the sensor state, and why if it is not READY
        the servo link, id, mode, encoder, voltage, temperature
        whether the carousel position is trusted
        what the transport has already seen

    IT MOVES NOTHING. Three commands, all reads: `ping`, `get_status`
    and - only when a servo is already connected - `servo_diagnostics`,
    which reads registers from the driver's own bounded whitelist. No
    EPROM write, no torque change, no illumination, no goal position.

    `--save-evidence` writes the whole thing as JSON so a failure can be
    diagnosed later, or compared against the next run, without anybody
    having to remember what the screen said.
    """
    report = {
        "captured_utc": utc_timestamp(),
        "port": link.port,
        "baud": link.baudrate,
        "client_expects_protocol": serial_link.EXPECTED_PROTOCOL_VERSION,
    }

    print()
    print("FREYA PREFLIGHT - read-only, nothing moves")
    print("=" * 60)

    # ---- identity -----------------------------------------------
    try:
        report["ping"] = link.ping()

    except (DeviceError, LinkError) as error:
        report["ping_error"] = {"code": error.code, "message": error.message}

        print("Board:      NO ANSWER - {}".format(error.code))
        print()
        print(error.message)

        _save_preflight(report, save_to)

        return 1

    link._note_identity(report["ping"])

    print("Board:      {} {}  (protocol {})".format(
        link.firmware_name or "?", link.firmware_version or "?",
        link.device_protocol_version))

    if link.protocol_mismatch:
        print("            !! MISMATCH - this client expects protocol {}"
              .format(link.protocol_mismatch["expected"]))
        print("            The device is not running this source.")

    report["protocol_mismatch"] = link.protocol_mismatch

    # ---- state ---------------------------------------------------
    try:
        status = link.get_status()
        report["status"] = status

    except (DeviceError, LinkError) as error:
        report["status_error"] = {"code": error.code,
                                  "message": error.message}
        print("Status:     UNAVAILABLE - {}".format(error.code))
        _save_preflight(report, save_to)

        return 1

    print("Sensor:     {}".format(ui_status.sensor_label(status)))
    print("Servo:      {}".format(ui_status.servo_link(status)))
    print("Carousel:   {}".format(ui_status.carousel_label(status)))

    sensor = status.get("sensor") or {}
    bus = sensor.get("bus") or {}

    if bus.get("addresses") is not None:
        print("I2C:        expected {}, found {}".format(
            sensor.get("address"), bus.get("addresses")))

    first_error = sensor.get("first_init_error")

    if first_error:
        print("Boot error: {}".format(first_error.get("code")))

    # ---- servo registers, only if a servo is already connected ----
    if ui_status.servo_online(status):
        try:
            diagnostics = link.servo_diagnostics()
            report["servo_diagnostics"] = diagnostics

            feedback = diagnostics.get("feedback") or {}
            counters = diagnostics.get("bus") or {}

            print("Servo id:   {}  mode {} ({})".format(
                diagnostics.get("id"), diagnostics.get("mode"),
                diagnostics.get("mode_name")))
            print("Carousel:   {}".format(
                "no origin - re-sync to set 0 deg"
                if feedback.get("angle_deg") is None
                else "{:+.1f} deg from origin".format(
                    feedback["angle_deg"])))
            print("Encoder:    {} cnt raw ({} deg within one turn), "
                  "origin {} cnt".format(
                      feedback.get("position_counts"),
                      feedback.get("shaft_deg"),
                      feedback.get("origin_counts")))
            print("Supply:     {} V, {} C".format(
                feedback.get("voltage_v"), feedback.get("temperature_c")))
            print("Servo bus:  {} tx / {} rx, {} retries, {} timeouts, "
                  "{} checksum".format(
                      counters.get("tx"), counters.get("rx"),
                      counters.get("retry"), counters.get("timeout"),
                      counters.get("checksum")))

        except (DeviceError, LinkError) as error:
            report["servo_diagnostics_error"] = {
                "code": error.code, "message": error.message}
            print("Servo diag: FAILED - {}".format(error.code))

    # ---- what this link has already seen --------------------------
    transport = {
        "corrupt_frames": link.corrupt_frames,
        "salvaged_frames": getattr(link, "salvaged_frames", None),
        "stale_frames": getattr(link, "stale_frames", None),
        "oversized_lines": getattr(link, "oversized_lines", None),
        "bytes_read": getattr(link, "bytes_read", None),
        "damage_reports": list(getattr(link, "damage_reports", []) or []),
    }
    report["transport"] = transport

    if link.corrupt_frames:
        print("Transport:  {} damaged frame(s) already this session"
              .format(link.corrupt_frames))

    print("=" * 60)

    _save_preflight(report, save_to)

    return 0


def _save_preflight(report, save_to):
    """Write the capture, and say where it went. Never raises."""
    if not save_to:
        return

    try:
        path = Path(save_to)

        if path.is_dir():
            path = path / "preflight-{}.json".format(
                report["captured_utc"].replace(":", "").replace("-", ""))

        path.parent.mkdir(parents=True, exist_ok=True)
        path.write_text(
            json.dumps(report, indent=1, sort_keys=True, default=str),
            encoding="utf-8")

        print("Evidence:   {}".format(path))

    except OSError as error:
        print("Evidence could NOT be written to {}: {}".format(
            save_to, error), file=sys.stderr)


def one_shot(link, command, payload_text):
    """
    Send one command and print the answer as JSON.

    For scripting and for diagnosis. It brings up no workflow, loads no
    database and asks no questions - which is what makes it useful when
    the question is "does the board answer at all?".
    """
    payload = {}

    if payload_text:
        try:
            payload = json.loads(payload_text)

        except ValueError as error:
            print("--payload is not valid JSON: {}".format(error),
                  file=sys.stderr)

            return 2

        if not isinstance(payload, dict):
            print("--payload must be a JSON object.", file=sys.stderr)

            return 2

    data = link.request(command, **payload)

    print(json.dumps(data, indent=2, sort_keys=True))

    return 0


def build_parser():
    parser = argparse.ArgumentParser(
        prog="rover_science_client.py",
        description="Freya soil analysis module - operator interface.",
    )
    parser.add_argument("--port", required=True,
                        help="serial port of the ESP32, e.g. COM4")
    parser.add_argument("--baud", type=int, default=DEFAULT_BAUDRATE)
    parser.add_argument("--timeout", type=float, default=DEFAULT_TIMEOUT,
                        help="seconds to wait for one command")
    parser.add_argument("--connect-timeout", type=float,
                        default=CONNECT_TIMEOUT,
                        help="seconds to wait for the first ping")
    parser.add_argument(
        "--preflight", action="store_true",
        help="read-only bench check: identity, firmware, sensor, servo, "
             "carousel, transport counters. Moves nothing and exits.")
    parser.add_argument(
        "--save-evidence", metavar="PATH",
        help="with --preflight, write the whole capture as JSON to a "
             "file or directory")
    parser.add_argument("--command",
                        help="send one command and exit")
    parser.add_argument("--payload",
                        help="JSON object of extra fields for --command")
    parser.add_argument(
        "--verbose", action="store_true",
        help="trace the transport: PORT OPEN, TX JSON, RX JSON, "
             "RX NON-JSON, TIMEOUT, PORT CLOSED",
    )

    return parser


def make_console_unbreakable():
    """
    Stop a character the terminal cannot encode from killing a screen.

    THE DEFECT THIS EXISTS FOR.

    Sample notes, locations, tasks and hypotheses are free text typed by
    the operator, and this is a Brno team: "vzorek z pouste, zluty
    pisek" arrives with hacek and carka in it, and an en dash comes free
    with most keyboards. Python encodes stdout using the LOCALE's
    encoding, so on a machine running under LANG=C - a systemd unit, a
    minimal container, a cron job, or a redirected pipe - that encoding
    is ASCII, and printing the note raises UnicodeEncodeError from
    inside print(). The records screen dies with a traceback over a
    character in a comment field.

    Reproduced: `print_full_sample` on a record whose location contains
    an en dash, with stdout at ASCII.

    WHY THE ENCODING IS LEFT ALONE AND ONLY THE ERROR HANDLER CHANGES.

    Forcing UTF-8 onto a terminal that is genuinely cp1252 would replace
    a crash with mojibake, which is a quieter way to be wrong. Changing
    only the handler keeps a UTF-8 terminal perfect - the normal Linux
    case - and turns the unrepresentable character into a visible
    `\\u010d` escape everywhere else. Nothing is silently lost: the
    ARCHIVE is written by json.dump with ensure_ascii=False through an
    explicit encoding="utf-8", so the stored text is unaffected by
    whatever the terminal can show.

    stdin is given the same treatment for the same reason: typing an
    accented character into a prompt should not raise UnicodeDecodeError
    out of input().
    """
    for stream in (sys.stdout, sys.stderr, sys.stdin):
        # A stream replaced by a test, a pipe wrapper or an IDE may not
        # be a TextIOWrapper at all, and reconfigure() is only on those.
        reconfigure = getattr(stream, "reconfigure", None)

        if reconfigure is None:
            continue

        try:
            reconfigure(errors="backslashreplace"
                        if stream is not sys.stdin else "replace")

        except (OSError, ValueError):
            # Detached, already closed, or a stream that will not be
            # reconfigured. The program runs; it just keeps whatever
            # handler it had.
            pass


def main(argv=None):
    make_console_unbreakable()

    args = build_parser().parse_args(argv)

    try:
        link = SerialLink(
            port=args.port,
            baudrate=args.baud,
            timeout=args.timeout,
            connect_timeout=args.connect_timeout,
            verbose=args.verbose,
        )

    except RuntimeError as error:
        print(error, file=sys.stderr)

        return 2

    # OPEN AND CLOSE IN ONE PLACE.
    #
    # Every exit path below - a normal quit, a failed ping, a timeout, a
    # malformed frame, a Science failure, a database failure, Ctrl+C, an
    # unhandled exception - passes through the same finally. Relying on
    # interpreter exit to release the port is what leaves COM4 held
    # after a crash and turns the next run into a PORT_BUSY that has
    # nothing to do with another program.
    try:
        link.open()

    except LinkError as error:
        print("{}: {}".format(error.code, error.message), file=sys.stderr)

        return 2

    try:
        if args.preflight:
            return preflight(link, args.save_evidence)

        if args.command:
            return one_shot(link, args.command, args.payload)

        return interactive(link)

    except DeviceError as error:
        print("The module refused the command: {} {}".format(
            error.code, error.message), file=sys.stderr)

        return 1

    except LinkError as error:
        print("{}: {}".format(error.code, error.message), file=sys.stderr)

        return 1

    except KeyboardInterrupt:
        print()

        return 0

    # Ctrl+D, a finished input script, or a dropped SSH session. The
    # same clean exit as Ctrl+C: there is nothing wrong, there is just
    # nobody left to ask. Reaching here is what lets the `finally`
    # below release the port - the loop that used to spin on EOF never
    # did, and left /dev/ttyUSB0 held by a client the operator believed
    # they had closed.
    except OperatorGone:
        print()

        return 0

    finally:
        link.close()


if __name__ == "__main__":
    sys.exit(main())

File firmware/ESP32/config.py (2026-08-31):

# config.py
#
# Hardware configuration for the ESP32 side of the Freya science module.
#
# ONE source of truth. No module may hardcode a value that appears here:
# a duplicated gain or integration setting is how the sensor ended up
# running at defaults while the firmware reported the intended values.
#
# Nothing scientific lives here. Analysis thresholds, the calibration ID
# and the database paths belong to firmware/BD/config.py, which never
# reaches the device.

FIRMWARE_NAME = "freya-science-module"
FIRMWARE_VERSION = "6.0.0"

# Bumped when the COMMAND SURFACE changes - a command added, removed or
# renamed, or a response field the PC depends on. 2 is the flat
# firmware with connect_servo/disconnect_servo; 1 was the package
# layout with select_servo and the capability table.
PROTOCOL_VERSION = 2

# Bumped when the shape of an acquisition response changes. 2 is the
# WHITE/UV/IR one-shot protocol with repeats; 1 was the single
# continuous-mode white spectrum.
ACQUISITION_PROTOCOL_VERSION = 2

# ==========================================
# I2C & AS7265x
# ==========================================
I2C_BUS = 0
I2C_SDA_PIN = 21
I2C_SCL_PIN = 22
I2C_FREQ = 100000

# Verified on the real board: the AS7265x master answers here.
AS7265X_ADDRESS = 0x49

# Acquisition settings. These are WRITTEN to the sensor and then READ
# BACK and verified during initialization, so what the PC is told is
# what the silicon is actually doing.
SENSOR_INTEGRATION_CYCLES = 100

# Gain: 0b00 = 1x, 0b01 = 3.7x, 0b10 = 16x, 0b11 = 64x
SENSOR_GAIN = 0b10

# Measurement mode:
#   0b10 = 6 channels per device, CONTINUOUS
#   0b11 = all channels, ONE-SHOT
#
# One-shot. Continuous mode free-runs, so a read can return a
# conversion that started before the illumination was switched - the
# spectrum and the lamp that produced it are not guaranteed to belong
# together. One-shot makes every acquisition deterministic: arm it
# after the LED is on and settled, wait for DATA_READY, read once.
SENSOR_MEASUREMENT_MODE = 0b11

# Illumination bulb current, per lamp.
#   0b00 = 12.5mA, 0b01 = 25mA, 0b10 = 50mA, 0b11 = 100mA
#
# Conservative 25 mA on all three, matching what the module has always
# run the white lamp at. Never raise these just to get bigger numbers -
# that changes the optical conditions the calibration was taken under.
WHITE_LED_CURRENT = 0b01
UV_LED_CURRENT = 0b01
IR_LED_CURRENT = 0b01

# Kept as the historical name for the white lamp current.
ONBOARD_LED_CURRENT = WHITE_LED_CURRENT

# Human readable names, used only when reporting hardware state.
SENSOR_GAIN_NAMES = {0: "1x", 1: "3.7x", 2: "16x", 3: "64x"}
SENSOR_LED_CURRENT_NAMES = {0: "12.5mA", 1: "25mA", 2: "50mA", 3: "100mA"}
SENSOR_MEASUREMENT_MODE_NAMES = {
    0: "4-channel", 1: "4-channel alt",
    2: "6-channel continuous", 3: "one-shot",
}

# ==========================================
# REPEATED ACQUISITION
# ==========================================
# A single reading is not a scientific measurement. Both counts are
# configurable and deliberately independent: calibration is done once
# and can afford to be slow, a rover sample cannot.
CALIBRATION_REPEATS = 10
SAMPLE_REPEATS = 3

# Pause between repeats within one block, so consecutive conversions
# are not correlated by the same electrical transient.
REPEAT_DELAY_MS = 60

# Upper bound accepted from the PC, as a runaway guard.
MAX_REPEATS = 25

# Seconds after reset before the I2C bus may be touched, so the 3.3 V
# rail and the AS7265x internal startup are finished.
#
# This does NOT delay the protocol. The board serves ping and
# get_status immediately; whatever remains of this wait is paid by the
# first command that actually needs the sensor. See
# sensor.py::SensorRuntime._await_power_on.
STARTUP_DELAY_SECONDS = 3

# Bounded sensor bring-up. A single failed attempt at boot must never
# become permanent runtime state, so initialization retries a few times
# and every later sensor operation may retry again on its own.
SENSOR_INIT_ATTEMPTS = 4
SENSOR_INIT_RETRY_MS = 400

# Bus-level scan retries inside one initialization attempt.
I2C_SCAN_ATTEMPTS = 3
I2C_SCAN_RETRY_MS = 150

# Longest wait for ONE virtual-register transaction.
VIRTUAL_REGISTER_TIMEOUT_MS = 1071

# Longest an entire sensor operation may take, however many
# transactions it is made of.
#
# ONE BOUNDED WAIT DOES NOT BOUND THEIR SUM. Bringing the AS7265x up
# runs about twenty virtual-register transactions, each containing two
# bounded waits, and the whole thing is retried SENSOR_INIT_ATTEMPTS
# times. A sensor that answers on the I2C bus but never sets its ready
# bit makes every one of those waits run to full length: measured on
# hardware, that took the firmware past three minutes without
# answering, which the PC could only read as a dead board.
#
# 8 seconds is generous for a healthy sensor - a good bring-up takes
# well under one - and short enough that a sick one is REPORTED rather
# than waited on.
SENSOR_OPERATION_BUDGET_MS = 8000
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

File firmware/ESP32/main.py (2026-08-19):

# main.py
#
# Application entry point for the Brno Mars Rover / Freya science module.
#
# It does three things and nothing else:
#
#     build the runtime state
#     build the protocol
#     serve
#
# PROTOCOL FIRST. Nothing between reset and the serving loop touches a
# peripheral - no I2C transaction, no UART, no settling delay, no retry
# loop. A board that cannot be reached cannot be diagnosed, so a broken
# sensor or an unpowered servo must never be able to make the module
# silent. Both are states the protocol REPORTS:
#
#     sensor      NOT_INITIALIZED until something needs it, then
#                 READY or UNAVAILABLE
#     servo       not connected until the operator connects it
#     carousel    position invalid until it is synchronized
#
# and in every one of those states ping, get_status and the diagnostics
# still answer.
#
# ESP32 responsibilities as a whole:
#   - AS7265x initialization, recovery and raw acquisition
#   - ST3215 communication and verified movement
#   - carousel physical movement and position state
#   - hardware status and the JSON protocol
#
# Scientific processing, White/Dark normalization, database comparison
# and persistent Sample storage run on the PC. This firmware never
# learns what material a sample resembles: it moves hardware, reads
# hardware and reports hardware.
#
# Transport:
#   newline-delimited JSON over USB / CP2102 using sys.stdin/sys.stdout.
#   stdout IS the protocol stream, so nothing here may print outside a
#   JSON frame.
#
# Deployment and terminal instructions: see Documentation/OPERATIONS.md

import time

from carousel import Carousel
from protocol import Protocol, debug
from sensor import SensorRuntime
from servo import ServoLink


class Hardware:
    """
    Everything the module owns, and nothing it does.

    Construction opens no bus and commands no peripheral: it creates
    three objects that each know how to bring their own hardware up
    later, on demand. That is what makes the protocol reachable one
    instant after reset.
    """

    def __init__(self):
        self.started_at = time.ticks_ms()

        # Brings itself up on the first command that needs a spectrum,
        # and retries from scratch after any failure.
        self.sensor = SensorRuntime()

        # No servo is connected at startup, and none is guessed at. A
        # reboot is exactly when someone may have unplugged the servo
        # or its external supply, so the operator connects it through
        # option [0] before the carousel will move at all.
        self.servo = ServoLink()
        self.carousel = Carousel(None)

    def uptime_ms(self):
        return time.ticks_diff(time.ticks_ms(), self.started_at)

    def shutdown(self):
        """
        Release the servo link on the way out, never raising.

        Torque is deliberately left alone: dropping to the REPL must
        not let the carousel turn and lose the position the operator
        synchronized.
        """
        try:
            self.servo.release("firmware stopped")

        except Exception as error:
            debug("could not release the servo link:", error)


# Module-level handles so the running instance can be inspected from
# the REPL after Ctrl+C:  import main; main.hardware.carousel.status()
hardware = None
service = None


def main():
    global hardware, service

    hardware = Hardware()
    service = Protocol(hardware)

    try:
        service.serve_forever()

    except KeyboardInterrupt:
        debug("command loop stopped by user")

    finally:
        hardware.shutdown()


if __name__ == "__main__":
    main()

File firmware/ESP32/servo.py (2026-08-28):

# servo.py
#
# The carousel actuator: a Waveshare ST3215 serial bus servo on UART2,
# its wire protocol, and its connection lifecycle.
#
# ONE actuator, ONE file. Earlier firmware spread this across a
# register table, an abstract backend contract, the driver and a
# manager that chose between backends. There is one actuator, and an
# abstraction with a single implementation is a second file to read
# before understanding the first.
#
# What survives is everything that was never about choosing a backend:
#
#   rotation vocabulary   an angle on a rotary axis still needs
#                         reducing to (-180, +180]
#   the wire protocol     checksums, packet framing and sign
#                         conventions, still pure functions that can be
#                         tested without a servo
#   the movement gate     nothing moves the carousel before the UART is
#                         open and the servo has answered. A carousel
#                         that turns because a driver object happened
#                         to construct is a carousel turning with no
#                         idea where it is.
#
# The connection is RUNTIME state. After a reboot nothing is connected,
# because a reboot is exactly when someone may have unplugged
# something.
#
# This module knows about a servo. It knows nothing about a carousel,
# slots, samples or geometry beyond the two angles the mechanism
# defines in config.

import time

import config


# ======================================================================
# errors
# ======================================================================

class ServoError(Exception):
    """
    Actuator fault carrying a machine-readable code.

    The driver raises subclasses of this, so the carousel can handle a
    movement failure through one except clause and the PC can turn the
    code into an instruction instead of a stack trace.

    super().__init__ - MicroPython cannot call Exception.__init__ unbound.
    """

    code = "SERVO_ERROR"

    def __init__(self, message, code=None, motion=None):
        super().__init__(message)

        self.message = str(message)

        if code is not None:
            self.code = str(code)

        # WHAT THE MECHANISM DID BEFORE THIS FAILURE.
        #
        # Observed on the Linux bench, 2026-08-24: a measurement's
        # 180 degree transfer failed with SERVO_POSITION_MISMATCH, and
        # the operator was told "carousel: nothing was moved" - while
        # the carousel had visibly turned. The failure had no way to
        # say otherwise, so every layer above it defaulted to the
        # safest-sounding sentence rather than the true one.
        #
        # "Nothing moved" and "something moved and I cannot prove
        # where it stopped" call for opposite physical actions from an
        # operator standing at the rover. They must never collapse
        # into one message, so every movement failure now carries the
        # evidence: whether a goal was written, and what the encoder
        # read before and after.
        self.motion = dict(motion or {})

    def as_dict(self):
        report = {"code": self.code, "message": self.message}

        if self.motion:
            report["motion"] = dict(self.motion)

        return report


class ServoNotSupportedError(ServoError):
    """The servo cannot do this. Not a fault - a capability."""

    code = "SERVO_NOT_SUPPORTED"


class ServoNotConnectedError(ServoError):
    """
    Nothing has opened the UART and confirmed the servo answers.

    Its own class because it is the one servo fault that is not a
    hardware problem: the operator has simply not run Carousel Setup
    yet, and the PC turns this code into that instruction.
    """

    code = "SERVO_NOT_CONNECTED"


# ======================================================================
# rotation vocabulary
# ======================================================================

# Direction labels, shared between the carousel and the driver.
#
# What "clockwise" MEANS physically is this driver's business: the
# ST3215 gets a positive or negative step count. Which way the CAROUSEL
# must turn to advance a slot number is a third, mechanical question
# and lives in config.CAROUSEL_FORWARD_DIRECTION.
CW = "cw"
CCW = "ccw"

DIRECTIONS = (CW, CCW)


def opposite(direction):
    """Return the direction opposite to the given one."""
    if direction == CW:
        return CCW

    if direction == CCW:
        return CW

    raise ServoError("unknown direction: {}".format(direction))


def direction_sign(direction):
    """+1 for clockwise, -1 for counter-clockwise."""
    if direction == CW:
        return 1

    if direction == CCW:
        return -1

    raise ServoError("unknown direction: {}".format(direction))


def centred_degrees(degrees):
    """
    Reduce an angle to (-180, +180].

    The carousel compares an expected angle against a measured one on a
    rotary axis, where 350 degrees and -10 degrees are the same place.
    Both sides go through here before they are subtracted.
    """
    return ((float(degrees) + 180.0) % 360.0) - 180.0


def validate_direction(direction):
    if direction not in DIRECTIONS:
        raise ServoError(
            "direction must be '{}' or '{}', not {}".format(
                CW, CCW, direction
            ),
            code="SERVO_BAD_DIRECTION",
        )

    return direction


# There is deliberately no capability table here.
#
# One existed while a second actuator was supported, so callers
# could ask "can this one measure its own position?" instead of
# testing its name. With one actuator every answer is a constant:
# the ST3215 has an encoder, verifies every movement against it,
# reports telemetry, and takes torque and mode commands. A
# dictionary of seven values that are all True is not information,
# it is seven branches that can never be taken.
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

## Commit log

2026-04-08 Managed project "MarsRover_ScienceTeam" created from AD
    [MarsRover_ScienceTeam.PrjPcb]
2026-07-15 Organize project strcuture and add firmware
    [01_POWER.SchDoc, 02_ESP32.SchDoc, 03_CONNECTION.SchDoc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]
2026-08-11 New system for 8-samples, nead calibration, broblem with sensor + nead clianing of code
2026-08-11 First working test, still nead adjustment with BD for samples, and synchonization
2026-08-13 Update firmware, host software and project files, still nead work on PWM saving samples ot BD, and cleaning code
    [as7265x-soil-analysis-module.PrjPcb]
2026-08-19 new deployment code, need to be cleaned
    [Exact_Science_Task_Rubric.xlsx]
2026-08-20 System is working, servo, sensor, next troubshooting of the system
2026-08-28 Answer a bare `id` line, so a host can identify the board before it knows the protocol
    The three Freya ESP32 boards -- science, drilling and astro-bio -- are all
    ESP32-DevKitC behind a CP2102 and are descriptor-identical: same 10c4:ea60,
    same Silicon Labs factory serial "0001", same product string, same bcdDevice.
    cp210x-cfg cannot write the EEPROM. They also collide in /dev/serial/by-id,
    where all three claim the same filename -- so with two attached that link
    resolves to an arbitrary board while looking perfectly unambiguous.
    ping already carries this module's identity, and that is the right place for
    it. The problem is purely one of ordering: a host cannot ask for ping without
    already kn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
    [protocol.py]
